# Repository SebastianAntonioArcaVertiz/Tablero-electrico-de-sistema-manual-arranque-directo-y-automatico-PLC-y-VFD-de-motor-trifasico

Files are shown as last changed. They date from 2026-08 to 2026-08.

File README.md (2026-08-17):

Este repositorio contiene la documentación técnica, los esquemas eléctricos y el código fuente para el diseño e implementación de un tablero de accionamiento para un motor asíncrono trifásico (0.5 HP). El sistema está diseñado para entornos exigentes, alojado en un gabinete con grado de protección IP67 e IK10, y cuenta con dos regímenes de operación protegidos por un enclavamiento estricto:

**\***   **Modo Manual:** Arranque directo a la red mediante control electromecánico (contactor AC-3 y relé térmico Clase 10).

**\***   **Modo Automático:** Control de transición de tres velocidades fijas, gobernado por un Controlador Lógico Programable (PLC) interactuando con un Variador de Frecuencia (VDF).

**Este proyecto fue desarrollado como parte del proyecto final del curso de ELECTRICIDAD INDUSTRIAL, de la escuela de Ingeniería Electrónica y Telecomunicaciones de la Universidad Nacional de Piura (UNP).**

**\***   **Controlador (PLC):** Schneider Zelio programado en lenguaje Ladder.

**\***   **Accionamiento (VDF):** SUSWE de 0.75 kW (1 HP), configurado para rampas suaves de 5 segundos.

**\***   **Normativa Eléctrica:** Dimensionamiento de conductores (14 AWG y 16 AWG) y protecciones selectivas con disyuntores de Curva C según el Código Nacional de Electricidad (CNE-Utilización) y la NTP 370.301 / IEC 60364-5-523.

**\***   **Normativa de seguridad:** Se cumple con los entándares de la ley 29783 y la gestion de seguridad y salud en el trabajo, se adjunta los documentos IPERC y ATS de prueba que se utilizaron y se entregaron en el proyecto.

**\***   **Simbología:** Estándar IEC 60617.

El repositorio consta de videos de demostración de cómo funciona el sistema, planos en AutoCAD y pdf, un informe que detalla la elección de componentes, normas utilizadas y evidencias de fabricación, y la documentación de seguridad que se siguió para el desarrollo del proyecto.

El algoritmo del PLC fue diseñado mediante el uso de marcas de memoria para permitir la transición directa entre velocidades sin necesidad de accionar un paro intermedio. La gestión binaria de salidas hacia el variador se estructura de la siguiente manera:

**\***   **Velocidad 1 (10 Hz):** Activa `Q1` energizando el borne `X0` (Señal maestra de giro).

**\***   **Velocidad 2 (20 Hz)**: Activa `Q1` y `Q2` energizando los bornes `X0` y `X2`.

**\***   **Velocidad 3 (30 Hz):** Activa `Q1`, `Q2` y `Q3` energizando los bornes `X0`, `X2` y `X3`.

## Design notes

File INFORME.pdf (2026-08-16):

### UNIVERSIDAD NACIONAL DE PIURA

FACULTAD DE CIENCIAS, ESCUELA PROFESIONAL DE INGENIERÍA ELECTRONICA ´

Y TELECOMUNICACIONES

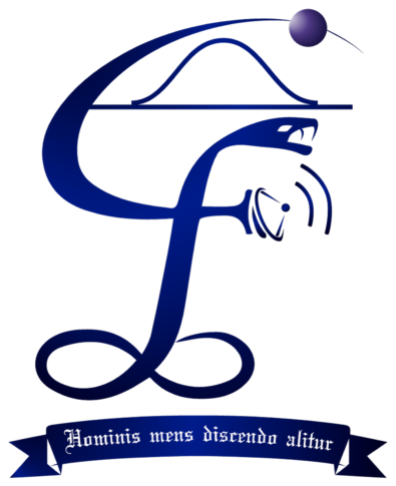
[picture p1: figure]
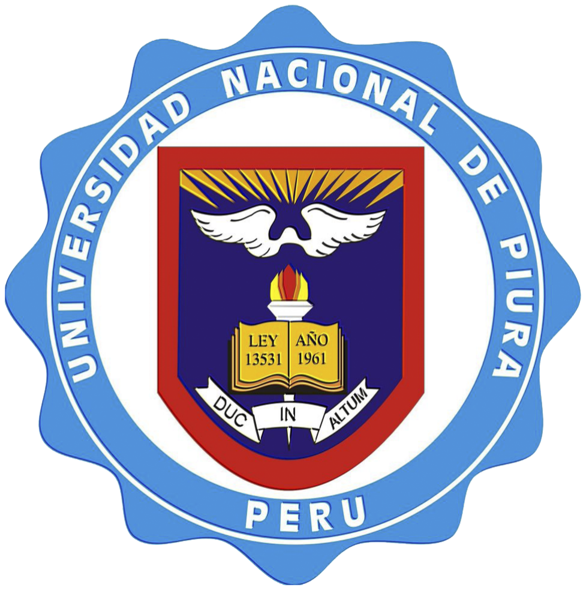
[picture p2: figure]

DISENO E IMPLEMENTACI ˜ | ON DE UN SISTEMA ´

## DE ARRANQUE MANUAL Y AUTOMATICO ´ MEDIANTE VARIADOR DE FRECUENCIA (VDF) PARA UN MOTOR TRIFASICO ´

CURSO: ELECTRICIDAD INDUSTRIAL
DOCENTE: ING. EDUARDO OMAR AVILA REGALADO CICLO: IX (2026-I)

ALUMNOS:
Alvarado Mendoza Jorge, Arca Vértiz Sebastián Antonio, Bernales Flores Joseph Emmanuel, Calle Flores Jesús Enrique, Calle Jiménez Jesús Manuel Santiago, Giron Alamo Klever Paul, Izquierdo Montenegro Juan Eduardo, Mauricio Apagueño Ney Junior, Merino Castro Jennifer Elian, Paiva Moscol Ronald Ignacio, Paredes Lopez Gheiler Stihuar, Rosales Sondor Ismael Alexander, Suárez Aquino Josué David, Vasquez Vigil Deyvi, Vilchez Sosa Djanira Isabel.

### PIURA – PERÚ JULIO DEL 2026

### Índice

1. Marco Normativo | 2
2. Cálculos de Diseño | 2
3. Selección de Componentes | 2
4. Lógica de Control y Programación Ladder | 6
5. Planos y Evidencias Adicionales | 8

### 1. Marco Normativo

El diseño y dimensionamiento del cuadro eléctrico se ciñe a las siguientes normativas:

Código Nacional de Electricidad (CNE-Utilización): La Regla 030-002 establece que la sección mínima para conductores de circuitos derivados de fuerza es de 2.5 mm² (14 AWG), mientras que para circuitos de control en tableros se permite un mínimo de 1.5 mm² (16 AWG).

NTP 370.301 / IEC 60364-5-523: Sustentan los métodos de instalación y las capacidades de transporte de corriente detallados en la Tabla 2 del CNE, homologando el diseño con estándares internacionales.

IEC 60617: Empleada para la simbología estandarizada en los diagramas.

IEC 60529 (IP67) e IEC 62262 (IK10): Aseguran la hermeticidad total contra polvo y agua temporal, además de la resistencia mecánica.

### 2. Cálculos de Diseño

### 2.1. Cálculo de la Corriente Nominal (In)

El cálculo se fundamenta en los datos de placa del motor asíncrono trifásico jaula de ardilla utilizado: Potencia P = 400 W (0,54 HP), Voltaje V = 220 V , factor de potencia cos ϕ = 0,70 y eficiencia η = 70 %.

In =

P
√
3 · V · cos ϕ · η

(1)

Sustituyendo los valores:

In =

400
√
3 · 220 · 0,70 · 0,70

=

400
186,71

≈ 2,14 A

A efectos de diseño y protecciones, se toma como referencia el valor de placa homologado: In = 2,47 A.

### 2.2. Dimensionamiento de Conductores

Circuito de Fuerza: Según la Sección 150 del CNE, el conductor debe soportar al menos el 125 % de la corriente nominal (Idisenõ = 3,08 A). Cumpliendo la Regla 030-002 por resistencia mecánica, se elige el calibre 14 AWG (2.5 mm²). Su ampacidad es de 20 A a 75°C.
Circuito de Mando: Con un consumo estimado de 1 A para el PLC y contactores, se aplica la excepción normativa del CNE seleccionando 16 AWG (1.5 mm²).

### 3. Selección de Componentes

### 3.1. Dimensionamiento de Protecciones Termomagnéticas (Curva C)

La protección contra sobrecargas y cortocircuitos se ha estructurado mediante cuatro interruptores termomagnéticos de Curva C, distribuidos bajo el principio de segregación de funciones y protección de conductores (IEC 60947-4-1):

Disyuntor General Trifásico (16 A, Curva C): Al emplear una curva C, el disparo magnético (protección instantánea contra cortocircuitos) se activa cuando la corriente se eleva entre 5 × In y 10 × In. Para una llave de 16 A, esto significa que el corte abrupto ocurrirá si la corriente supera el rango de 80 A a 160 A. Dado que el pico transitorio de arranque del motor es de apenas 14,82 A, este valor cae cómodamente en la zona de tolerancia térmica inicial de la curva, impidiendo que el disyuntor salte al arrancar la máquina. La elección de 16 A, además de tolerar el arranque, cumple estrictamente la función de proteger el conductor de 14 AWG (cuya ampacidad es 20 A) garantizando la relación de seguridad Illave ≤ Icable.

Disyuntor General Monofásico de Mando (10 A): Actúa como protección de cabecera para toda la etapa de control y pupitre, protegiendo adecuadamente el cableado general de 16 AWG.

Disyuntor Monofásico de Automatización (2 A): Dedicado exclusivamente a aislar y proteger la instrumentación electrónica sensible (alimentación del PLC y el VDF).

Disyuntor Monofásico Manual (2 A): Protege el circuito electromecánico tradicional, ubicado antes del selector de 3 posiciones.

Esta topología asegura selectividad: un fallo en la bobina de un contactor o una luz piloto activará la zona magnética del disyuntor de 2 A, sin afectar la llave general de mando de 10 A.

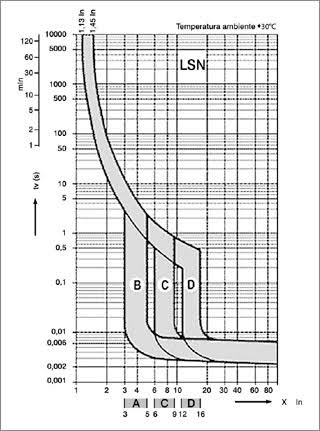
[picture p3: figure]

Figura 1: Curvas de disparo magnético (B, C y D). El sistema utiliza disyuntores de Curva C, cuya banda verde central muestra que el disparo por cortocircuito se efectúa entre 5In y 10In.

### 3.2. Selección del Contactor (Categoría AC-3)

Al tratarse de un motor trifásico jaula de ardilla cuyo corte se realiza a motor lanzado, la norma clasifica esta aplicación bajo la categoría de empleo AC-3. En esta categoría, la intensidad de cierre puede alcanzar hasta 6 veces la corriente nominal (6 × In):

Iarranque = 6 × 2,47 A ≈ 14,82 A

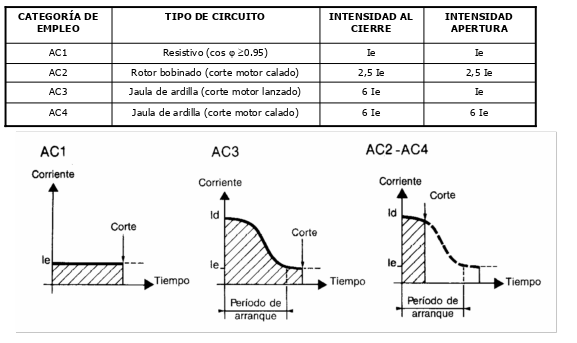
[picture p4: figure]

Figura 2: Tabla de categorías de empleo para circuitos. Se resalta la categoría AC-3.

Según la curva de robustez eléctrica, para manejar estos picos de casi 15 A, teóricamente bastaría con un contactor modelo LC1-D09A65. Sin embargo, en función a la disponibilidad de inventario en el mercado local y para asegurar una mayor vida útil, se optó por instalar un LC1D32.

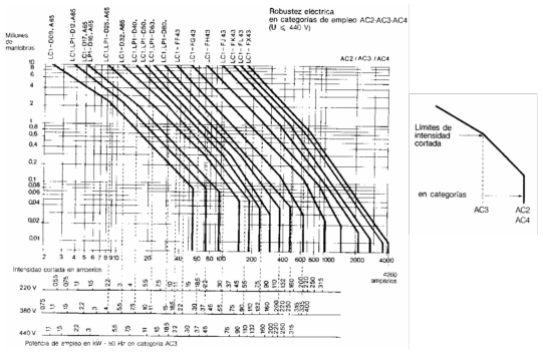
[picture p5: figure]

Figura 3: Curvas de robustez eléctrica para contactores en categoría AC-3.

### 3.3. Selección del Relé Térmico (Clase 10)

Se seleccionó un relé térmico de Clase 10. La curva de disparo de esta clase garantiza que, ante una hipotética sobrecorriente de 7 veces la corriente nominal (rotor bloqueado), el dispositivo desconectará el circuito en un lapso máximo de 10 segundos, previniendo daños térmicos severos en los devanados del motor. Como nuestra In es de 2.47 A, se seleccionó un modelo con un rango de regulación entre 1.6 A y 2.5 A, posicionando la manecilla al máximo para operar de manera óptima.

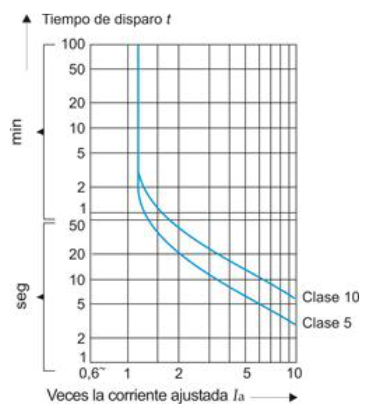
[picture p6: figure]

Figura 4: Curva característica de disparo para relé térmico Clase 10.

### 3.4. Variador de Frecuencia (VDF)

Para el modo automático, se seleccionó un VDF de la marca SUSWE con una potencia de 0.75 kW (1 HP). Esta capacidad otorga un excelente margen térmico y operativo para controlar el motor de 0.5 HP.

### 4. Lógica de Control y Programación Ladder

El sistema automático está gobernado por un PLC Schneider Zelio. La arquitectura de su programación en lenguaje Ladder se basa en el uso de marcas de memoria internas que actúan como ”momentos.operativos (M1, M2 y M3).

### 4.1. Momentos y Enclavamientos

Cada uno de estos momentos se activa al recibir la señal de los pulsadores conectados a las entradas (I1, I2 e I3). Una característica fundamental de este diseño es la transición directa: las líneas de código cuentan con contactos normalmente cerrados (NC) cruzados de las demás entradas. Esto asegura que se pueda cambiar de una velocidad a otra sin necesidad de pasar por el estado de detención previa. El botón de parada está configurado como un contacto Normalmente Abierto (NA) (I4), y al presionarse en cualquier momento, abre el circuito e interrumpe los enclavamientos.

### 4.2. Gestión de Salidas (VDF SUSWE)

Para comandar el variador de frecuencia, se utilizan las salidas tipo relé del PLC (Q1, Q2 y Q3). Estas salidas son alimentadas por los 24 VDC suministrados por la propia fuente interna del variador y se dirigen hacia sus terminales digitales de control (X0, X2 y X3). El terminal X1 fue deliberadamente omitido ya que su función predeterminada es la inversión de giro.
La combinación secuencial de estas salidas determina las velocidades:

Velocidad 1 (10 Hz): Al ejecutar el momento M1, la lógica activa únicamente la salida Q1. Esto energiza el borne X0 del variador, siendo la señal maestra que enciende el equipo y lo sitúa automáticamente en la primera velocidad preestablecida.

Velocidad 2: Al ejecutar el momento M2, la lógica acciona en paralelo las salidas Q1 y Q2. Al recibir tensión simultánea en X0 y X2, el variador acelera hasta la segunda consigna.

Velocidad 3: Al ejecutar el momento M3, la red de contactos habilita las tres salidas simultáneamente (Q1, Q2 y Q3). Al energizarse X0, X2 y X3, el variador de frecuencia opera en el tercer nivel de velocidad configurado.

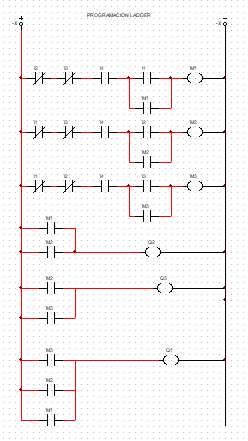
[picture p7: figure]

Figura 5: Diagrama de programación Ladder implementado en el PLC Zelio, mostrando los momentos de memoria y la activación combinada de salidas.

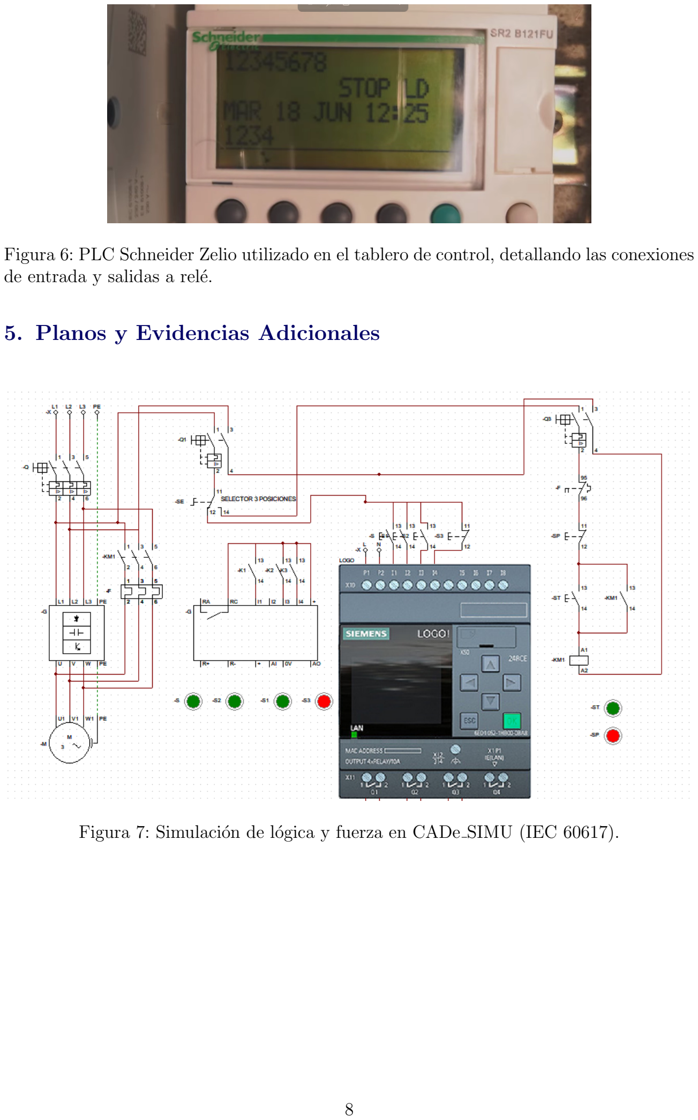
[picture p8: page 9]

Figura 6: PLC Schneider Zelio utilizado en el tablero de control, detallando las conexiones de entrada y salidas a relé.

### 5. Planos y Evidencias Adicionales

Figura 7: Simulación de lógica y fuerza en CADe SIMU (IEC 60617).

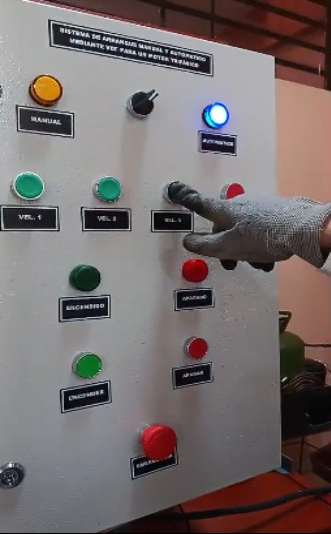
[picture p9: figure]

Figura 8: Gabinete hermético IP67 (Vista exterior) y botonera frontal.

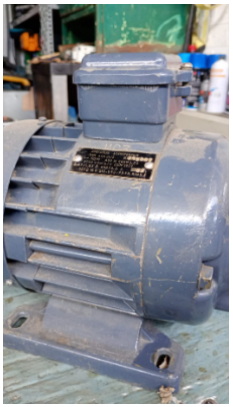
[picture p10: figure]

Figura 9: Motor asíncrono trifásico de prueba.

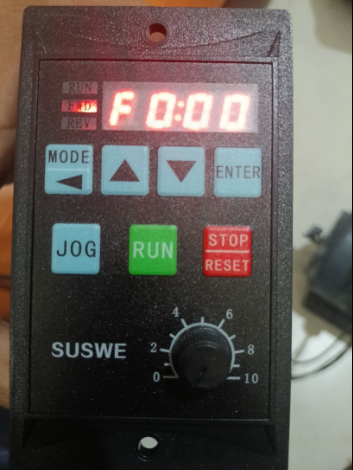
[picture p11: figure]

Figura 10: Variador de Frecuencia SUSWE (0.75 kW) y su parametrización.

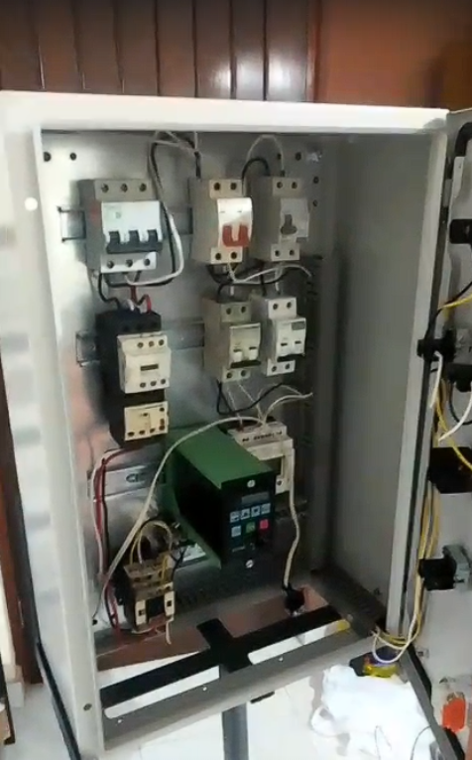
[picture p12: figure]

Figura 11: Distribución interna del gabinete eléctrico.

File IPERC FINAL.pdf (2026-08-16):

DISEÑO E IMPLEMENTACIÓN DE UN SISTEMA DE ARRANQUE MANUAL Y AUTOMÁTICO MEDIANTE VARIADOR DE FRECUENCIA (VDF) PARA UN

## MOTOR TRIFÁSICO

Proceso / Área | Electricidad industrial - Presentación de proyecto
Actividad principal | Instalación, cableado y puesta en marcha de tablero de arranque manual/automático con VDF
Equipos involucrados | Armario/gabinete eléctrico, IG 3~, IE 2~, IG2~/ID2~, contactor, relé térmico, PLC, VDF, motor trifásico, pulsadores, luces piloto, conmutador manual/automático
Fecha | 22/07/2026
Elaborado por | Alvarado Mendoza Jorge
| Arca Vértiz Sebastián Antonio
| Bernales Flores Joseph Emmanuel
| Calle Flores Jesús Enrique
| Calle Jiménez Jesús Manuel Santiago
| Giron Alamo Klever Paul
| Izquierdo Montenegro Juan Eduardo
| Mauricio Apagueño Ney Junior
| Merino Castro Jennifer Elian
| Paiva Moscol Ronald Ignacio
| Paredes Lopez Gheiler Stihuar
| Rosales Sondor Ismael Alexander
| Suárez Aquino Josué David
| Vasquez Vigil Deyvi
| Vilchez Sosa Djanira Isabel
Evaluado por | Msc. Eduardo Omar Ávila Regalado

# IPERC - IDENTIFICACIÓN DE PELIGROS, EVALUACIÓN Y CONTROL DE RIESGOS

## A. ÍNDICES PARA DETERMINAR EL NIVEL DE PROBABILIDAD

Índice | Personas Expuestas (PE) | Procedimientos existentes (PR) | Capacitación (CAP) | Exposición al Riesgo (ER)
1 | De 1 a 3 | Existen, son satisfactorios y suficientes | Personal entrenado, conoceelpeligro y lo previene | Al menos 1 vez al año (esporádica)
2 | De 4 a 12 | Existenparcialmente yno son satisfactorios o suficientes | Personal parcialmente entrenado, conoce el peligro pero no adopta acciones de control | Al menos 1 vez al mes (eventual)
3 | Más de 12 | No existen | Personal noentrenado, no conoceel peligro ni cómo actuar | Diaria (permanente)

## Índice de Probabilidad (IP) = PE + PR + CAP + ER → Bajo: 4-8 | Medio: 9-12 | Alto: 13-16

Índice | Severidad | Descripción
1 | Ligeramente Dañino | Lesión leve sin incapacidad (golpes, cortes menores, contactos eléctricos de baja tensión sin daño mayor)
2 | Dañino | Lesión con incapacidad temporal (quemaduras, choque eléctrico con recuperación,daño aequiporeparable)
3 | Extremadamente Dañino | Lesiónconincapacidad permanente o muerte (electrocución, arco eléctrico, incendio/explosión)
Rango NR | Nivel de Riesgo | ¿Riesgo Significativo?
4 | TRIVIAL | NO
5 - 8 | TOLERABLE | NO
9 - 16 | MODERADO | SÍ
17 - 24 | IMPORTANTE | SÍ
25 - 36 | INTOLERABLE | SÍ

## CRITERIOS PARA LA EVALUACIÓN DEL RIESGO (Probabilidad x Severidad)

## C. NIVEL DE RIESGO = ÍNDICE DE PROBABILIDAD (IP) x ÍNDICE DE SEVERIDAD (IS)

## B. ÍNDICE DE SEVERIDAD (CONSECUENCIA)

MATRIZ IPERC - Sistema de Arranque Manual y Automático mediante VDF para Motor Trifásico

N° | Actividad / Tarea | Peligro | Riesgo (consecuencia) | PE | PR | CAP | ER | IP (Probabili dad) | IS (Severid ad) | NR (IP x IS) | Nivel de Riesgo | ¿Riesgo Significativ o? | Medidas de Control Propuestas
1 | Traslado e instalación del armario/gabinete eléctrico en el área de presentación | Manipulación manual de estructura metálica pesada; bordes y cantos cortantes del gabinete | Golpes, cortes o atrapamiento de manos y pies | 2 | 2 | 2 | 2 | 8 | 1 | 8 | TOLERABLE | NO | Usar guantes de cuero y calzado de seguridad; trasladar el gabinete entre 2 personas; verificar punto de anclaje/nivelación antes de soltar.
2 | Instalación y conexionado de las protecciones: IG 3~ (potencia), IE 2~ (mando arranque directo), IG2~/ID2~ (PLC) | Contacto directo o indirecto con partes energizadas; posible arco eléctrico al ajustar bornes | Electrocución, quemaduras por arco eléctrico | 2 | 2 | 2 | 2 | 8 | 3 | 24 | IMPORTANTE | SI | Verificar ausencia de tensión con multímetro/detector antes de manipular; ejecutar bloqueo y etiquetado (LOTO); usar herramientas con aislamiento dieléctrico y EPP dieléctrico.
3 | Montaje y cableado de contactor y relé térmico para arranque directo manual | Cortocircuito por error de conexión; contacto con bornes energizados durante pruebas | Quemaduras, choque eléctrico, daño al equipo | 2 | 2 | 2 | 2 | 8 | 2 | 16 | MODERADO | SI | Ajustar el relé térmico según corriente nominal del motor antes de energizar; revisar diagrama unifilar; realizar prueba en vacío antes de energizar con carga.
4 | Conexión de cableado de control entre el PLC y el VDF (entradas/salidas digitales) | Energía residual almacenada en capacitores del VDF; error en polaridad/asignación de señales | Descarga eléctrica al manipular el variador, daño al PLC o al VDF | 2 | 2 | 2 | 2 | 8 | 2 | 16 | MODERADO | SI | Esperar el tiempo de descarga indicado por el fabricante del VDF (mínimo 5 minutos) antes de manipular bornes de potencia; verificar tensión residual con multímetro; seguir el manual de conexionado del fabricante.
5 | Instalación de pulsadores, luces de señalización y conmutador manual/automático en el frente del gabinete | Contacto con tensión de mando (24V/220V); conexión cruzada entre modo manual y automático | Choque eléctrico leve, cortocircuito, activación simultánea de dos circuitos | 2 | 2 | 2 | 2 | 8 | 2 | 16 | MODERADO | SI | Desenergizar el circuito de mando antes de cablear; verificar mediante diagrama que el conmutador aísla eléctricamente ambos modos (manual/automático) sin superposición.
6 | Conexión del VDF al motor trifásico para la demostración de arranque automático | Arranque inesperado del motor durante el conexionado o pruebas; partes rotativas en movimiento | Atrapamiento, golpes por movimiento súbito del motor | 2 | 2 | 2 | 2 | 8 | 2 | 16 | MODERADO | SI | Bloquear el acople/eje del motor o mantenerlo sin carga mecánica durante la demostración; delimitar el área con cinta de seguridad; nadie debe tener las manos cerca del eje al energizar.
7 | Conexión del circuito de arranque directo manual al motor para la demostración | Corriente de arranque elevada (Ia arranque directo); calentamiento de conductores y contactos | Quemaduras, inicio de incendio, daño al aislamiento del motor | 2 | 2 | 2 | 2 | 8 | 2 | 16 | MODERADO | SI | Verificar el dimensionamiento de conductores y protecciones para la Ia de arranque; limitar el tiempo de la demostración; tener extintor tipo C cerca del área.
8 | Energización y puesta en marcha del sistema completo (pruebas manuales y automáticas) frente al jurado/público | Falla eléctrica no detectada, cortocircuito o falso contacto durante la prueba en vivo | Electrocución, arco eléctrico, quemaduras, incendio | 2 | 2 | 2 | 3 | 9 | 3 | 27 | INTOLERABLE | SI | Realizar prueba de continuidad y aislamiento antes de la presentación; delimitar zona de seguridad frente al gabinete; tener un interruptor de parada de emergencia accesible; contar con extintor tipo C.
9 | Desenergización del sistema y orden del área al finalizar la presentación | Energía residual en capacitores del VDF o del sistema de control no descargada | Descarga eléctrica al manipular el equipo asumiéndolo apagado | 2 | 1 | 2 | 1 | 6 | 2 | 12 | MODERADO | SI | Abrir la protección general (IG 3~) y verificar ausencia de tensión antes de guardar o desconectar el gabinete; esperar tiempo de descarga del VDF.
10 | Uso de herramientas manuales y eléctricas (destornilladores, pelacables, multímetro) durante el montaje | Herramientas en mal estado, no aisladas o inadecuadas para trabajo eléctrico | Cortes, lesiones en manos, contacto eléctrico a través de la herramienta | 2 | 2 | 2 | 2 | 8 | 1 | 8 | TOLERABLE | NO | Inspeccionar herramientas antes de usarlas; emplear herramientas certificadas con aislamiento dieléctrico (1000V) para trabajos eléctricos.

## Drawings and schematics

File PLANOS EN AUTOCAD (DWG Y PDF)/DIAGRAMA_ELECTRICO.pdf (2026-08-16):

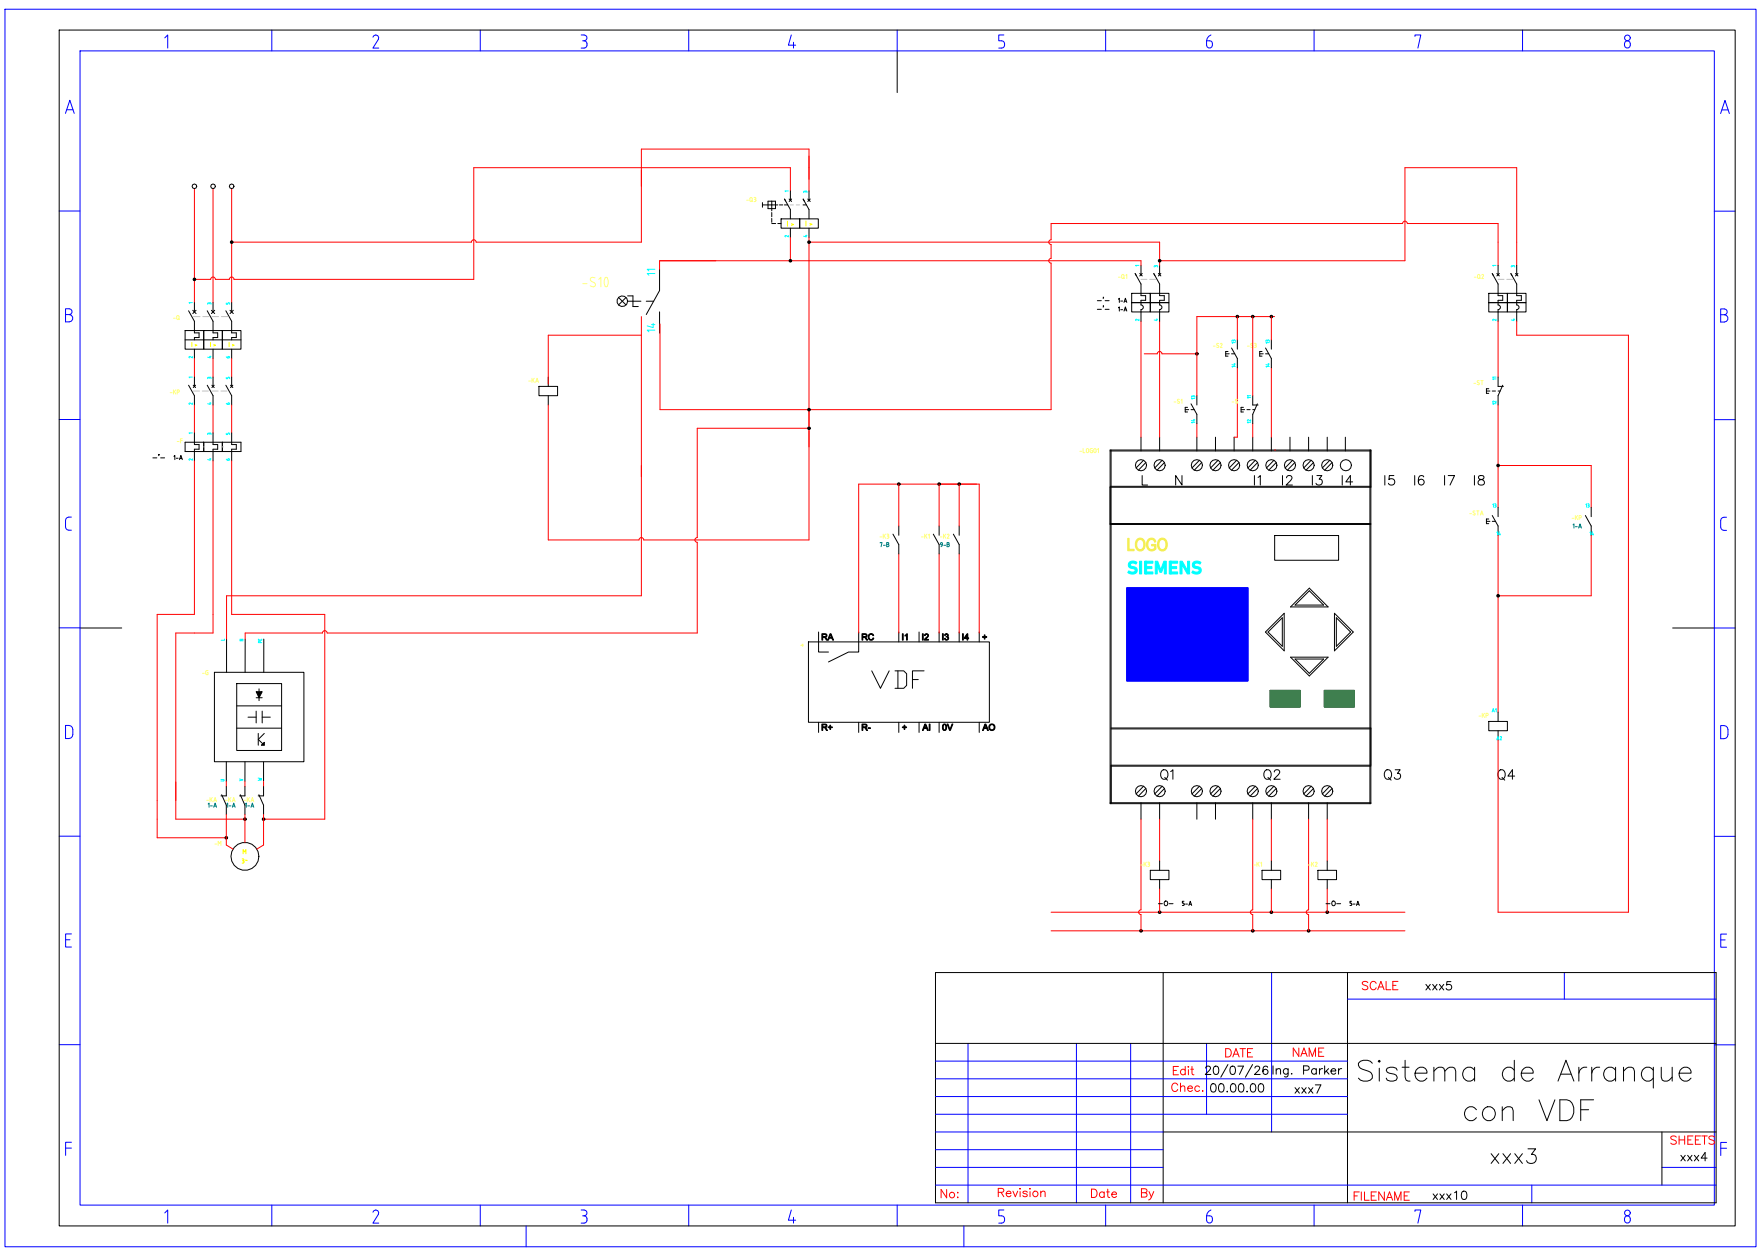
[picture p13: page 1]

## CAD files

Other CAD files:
PLANOS EN AUTOCAD (DWG Y PDF)/DIAGRAMA_ELECTRICO.dwg
